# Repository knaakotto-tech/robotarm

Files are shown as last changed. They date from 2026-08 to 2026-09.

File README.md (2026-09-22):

# robotarm

**C++ control software for a custom 5-DOF robotic arm, written from scratch — no vendor SDK.**






<!-- TODO: drop a photo or a short GIF of the arm here -->
<!-- ![The arm](docs/arm.jpg) -->

---

## What this is

A 5-servo robotic arm driven by Feetech STS3215 bus servos on a Raspberry Pi 5.
Mechanics, CAD and control software are all my own work.

The point of the project is the software. Feetech ships an SDK; this repository
deliberately does not use it. Every layer — serial port setup, packet framing,
checksums, register access, joint math — is implemented here, so that each byte
on the wire is something I can explain.

## Architecture

Each layer only talks to the one directly below it. The bottom is an abstract
interface, which is what makes everything above it testable without hardware.

```mermaid
flowchart TD
    A["apps/ — ping, move_test, calibrate_middle, measure_limits, ..."] --> B["Joint — degrees ↔ ticks, software limits"]
    A --> C["ServoBus — read_register / write_register"]
    B -.-> C
    C --> D["protocol — build_packet / parse_response / checksum"]
    D --> E["Transport (abstract) — write / read"]
    E --> F["SerialTransport — termios, 1 Mbit/s, 8N1"]
    E --> G["MockTransport — hex dump + canned replies"]
```

`MockTransport` is not a testing afterthought: it prints the exact bytes a command
would put on the bus and returns a prepared answer. When a servo goes quiet, running
the same sequence against the mock says immediately whether the problem is in the
code or in the hardware.

The `Joint` layer is currently pure math (dashed arrow). The `Arm` layer that
coordinates several joints over one bus is the next piece.

## Wire protocol

Feetech servos speak a Dynamixel-style protocol over a half-duplex serial bus:

```
0xFF 0xFF   ID   LENGTH   INSTRUCTION   PARAM ...   CHECKSUM
```

* `LENGTH` = number of parameters + 2
* `CHECKSUM` = bitwise complement of the sum of all bytes from `ID` onwards
  (the two header bytes are not included)

Instructions used so far: `0x01` PING, `0x02` READ, `0x03` WRITE.

Register addresses and their widths live in
[`include/robotarm/registers.hpp`](include/robotarm/registers.hpp) as named
constants — `R_GOAL_POSITION` instead of `42`, with the width carried alongside
the address so the bus layer can reject a malformed write before it is sent.

## Hardware

| Part | Detail |
| --- | --- |
| Servos | 5× Feetech STS3215 (12 V, C018, 1:345), IDs 1–5 |
| Bus adapter | Waveshare Bus Servo Adapter A, USB mode → `/dev/ttyACM0` |
| Controller | Raspberry Pi 5 |
| Power | 12 V / 5 A |
| Mechanics | Custom design, printed on a Bambu Lab A1 |

## Repository layout

```
robotarm/
├── include/robotarm/   # headers — what a class can do
├── src/                # implementation — how it does it
├── apps/               # small executables, one per experiment
├── cad/                # OpenSCAD models (servo library, fit test)
└── CMakeLists.txt
```

## Build and run

```bash
git clone https://github.com/knaakotto-tech/robotarm.git
cd robotarm
cmake -B build
cmake --build build
```

Targets that need no hardware — these run anywhere:

```bash
./build/mock_test        # dumps the bytes a command would send
./build/protocol_test    # checksum, packet building, joint math
./build/bus_test         # ServoBus against MockTransport
```

Targets that need a connected servo bus:

```bash
./build/ping              # ping servo ID 1
./build/move_test         # enable torque, drive to both ends, read position back
./build/calibrate_middle  # re-centre a servo on its mechanical middle
./build/measure_limits    # torque off, move a joint by hand, record min/max ticks
```

On Linux the user needs access to the serial device:

```bash
sudo usermod -aG dialout $USER   # then log out and back in once
```

On macOS use the `/dev/cu.*` device, never `/dev/tty.*` — the latter blocks on
open while waiting for a modem signal that never arrives.

## Status

- [x] `Transport` interface + `MockTransport`
- [x] `SerialTransport` (termios, 1 Mbit/s, raw mode, 100 ms read timeout)
- [x] Protocol layer — packet building, checksum, response parsing
- [x] Register map with address + width
- [x] `ServoBus` — read/write registers, verified against live servos
- [x] Servo IDs 1–5 assigned and commissioned
- [x] Joint layer — `degrees_to_ticks` / `ticks_to_degrees`, round-trip tested
      across the full angle range and both directions
- [x] All five servos re-centred with the built-in middle-point calibration
- [x] Tool to measure the real travel range of each joint by hand
- [ ] Per-joint limits filled in from the measurements
- [ ] Move to a defined rest position before torque is released
- [ ] `Arm` layer — several joints, synchronised writes
- [ ] Interpolation and kinematics
- [ ] Input layer (gamepad or web UI)

## Design notes

A few decisions that shaped the rest of the code:

* **Structured return types, not `bool`.** `read_register` returns a `Response`
  carrying id, error byte, payload and a validity flag; `degrees_to_ticks` returns
  a `TickResult`. The caller decides what to do with a failure — nothing is
  clamped silently and nothing throws.
* **Length checks before indexing.** In `parse_response`, the `size() < 6` guard
  has to come before comparing against the length byte, otherwise the subtraction
  wraps around on an unsigned type and a short reply passes as valid.
* **The zero point lives in the servo, not in software.** All five servos were
  re-centred using the STS3215's built-in middle-point calibration, so `zero_ticks`
  is 2048 for every joint and that position is the arm standing upright. Joints 2
  and 3 travel more than 180°, which would otherwise have put the 4095 → 0 tick
  wraparound in the middle of their working range. Repositioning the servo horn
  mechanically would have achieved the same, but has to be redone whenever a
  bracket changes.
* **Software end stops live in the joint layer.** A joint driven past its
  mechanical limit works ~30 kg·cm against its own bracket. The limit check
  happens before a packet is ever built.
* **`ServoBus` holds a `Transport&`.** A bus without a transport is not a state
  worth representing, so the reference member makes it impossible to construct one.

## References

* Feetech STS3215 datasheet (ST-3215-C018) — register map and protocol
* Waveshare Bus Servo Adapter A documentation

## License

Licensed under the Apache License 2.0 — see [LICENSE](LICENSE).

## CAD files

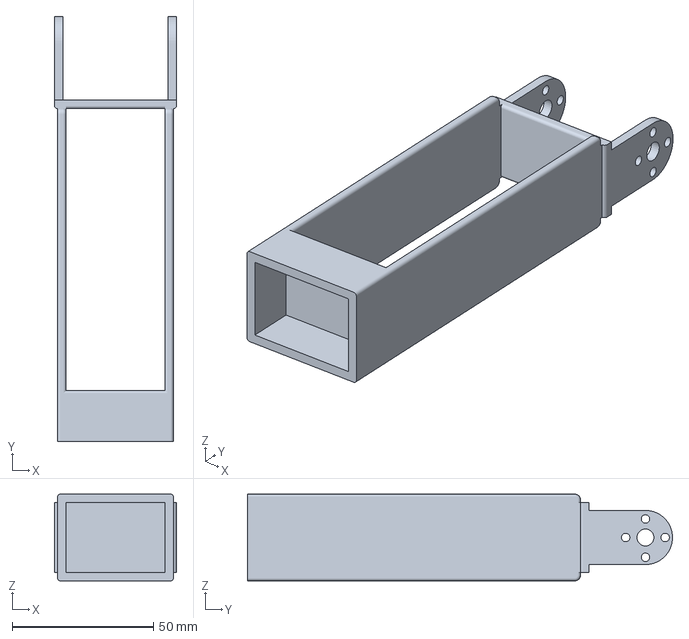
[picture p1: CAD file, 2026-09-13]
cad/zusammmengesetzterArmTeil-Assembly.3mf
43.3 x 150.6 x 30.7 mm

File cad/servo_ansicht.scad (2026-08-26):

// =====================================================================
//  servo_ansicht.scad  --  nur zum Anschauen
//
//  sts3215.scad ist eine Bibliothek und zeichnet absichtlich nichts.
//  Diese Datei bindet sie ein und ruft die Module auf, damit du das
//  Modell sehen kannst. Sie geht nie in ein Bauteil ein.
// =====================================================================

include <sts3215.scad>

// Der Servo
sts3215();

// Wellenachse: der Ursprung des Koordinatensystems
color("red")
    translate([0, 0, -SERVO_H - 12])
        cylinder(d = 1.0, h = SERVO_H + 26);

// Die vier Montageloecher an ihrer berechneten Position
color("blue")
    sts3215_loecher(tiefe = SERVO_H + 20, d = HOLE_D);

// Das Lochbild des Servohorns, auf der Wellenseite
color("green")
    translate([0, 0, SHAFT_H])
        horn_loecher(tiefe = 6);

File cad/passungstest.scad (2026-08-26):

// =====================================================================
//  passungstest.scad  --  Teil 1
//
//  Zweck: herausfinden, wie viel Spiel dein Drucker braucht, damit der
//  STS3215 saugend in einer Tasche sitzt.
//
//  Drei Taschen mit unterschiedlichem Spiel nebeneinander. Einmal
//  drucken, den Servo in allen dreien probieren. Die Tasche, in die er
//  ohne Werkzeug reingeht und in der er nicht wackelt, gewinnt.
//  Diesen Wert traegst du dann in sts3215.scad bei FIT ein -- ab da
//  passt jede Halterung, die wir daraus bauen.
//
//  Warum ueberhaupt Spiel noetig ist: ein 3D-Drucker legt heissen
//  Kunststoff ab. Beim Abkuehlen schrumpft er, und an Innenecken
//  quillt Material leicht nach innen. Eine Tasche, die im Modell exakt
//  45.23 mm hat, kommt real bei etwa 44.9 raus -- der Servo geht nicht
//  rein. Wie stark der Effekt ausfaellt, haengt an Duese, Material und
//  Temperatur und ist deshalb bei jedem Drucker anders. Man misst es
//  einmal aus, statt zu raten.
// =====================================================================

include <sts3215.scad>

SPIELE  = [0.15, 0.30, 0.45];   // getestete Werte, Spiel pro Seite in mm

WAND    = 3.2;    // Wandstaerke rund um jede Tasche
LABEL   = 9;      // Streifen an der Vorderseite fuer die Beschriftung
HOEHE   = 12;     // Bauteilhoehe; reicht zum Beurteilen und spart Zeit
SCHRIFT = 5;      // Schriftgroesse
GRAVUR  = 0.6;    // Gravurtiefe

// Breite einer Zelle und laufender Versatz
function zell_breite(i) = SERVO_L + 2*SPIELE[i] + 2*WAND;
function versatz(i)     = (i <= 0) ? 0 : versatz(i-1) + zell_breite(i-1);

// ---------------------------------------------------------------------
//  Eine Zelle: Rahmen mit durchgehender Tasche und Beschriftung
// ---------------------------------------------------------------------
module zelle(spiel) {
    tasche_l = SERVO_L + 2*spiel;
    tasche_w = SERVO_W + 2*spiel;
    aussen_l = tasche_l + 2*WAND;
    aussen_w = tasche_w + 2*WAND + LABEL;

    difference() {
        cube([aussen_l, aussen_w, HOEHE]);

        // Tasche geht durch: so kannst du den Servo wieder
        // rausdruecken, statt ihn rauszuhebeln
        translate([WAND, LABEL + WAND, -1])
            cube([tasche_l, tasche_w, HOEHE + 2]);

        // Wert in die Oberseite gravieren
        translate([aussen_l/2, LABEL/2, HOEHE - GRAVUR])
            linear_extrude(GRAVUR + 1)
                text(str(spiel), size = SCHRIFT,
                     halign = "center", valign = "center");
    }
}

for (i = [0 : len(SPIELE) - 1])
    translate([versatz(i), 0, 0])
        zelle(SPIELE[i]);

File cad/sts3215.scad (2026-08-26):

// =====================================================================
//  sts3215.scad  --  Bibliothek: Feetech STS3215 (Variante C018)
//
//  Diese Datei zeichnet von sich aus nichts. Sie stellt nur Konstanten
//  und Module bereit, die andere Dateien per include einbinden.
//  Genau wie ein Header in C++: er sagt, was es gibt, aber er ist kein
//  Programm.
//
//  Das Servo-Modell ist kein Detailabbild, sondern die Huellkontur.
//  Fuer eine Halterung ist genau das richtig -- die Tasche muss den
//  groessten Querschnitt aufnehmen, die Kuehlrippen interessieren nicht.
//
//  Koordinaten-Ursprung: Wellenachse, auf Hoehe der Gehaeuseflaeche
//    +Z = Richtung der Abtriebswelle
//    +X = Laengsrichtung, weg vom Getriebe (zum Motorende)
//    +Y = Breite
//
//  Der Ursprung liegt bewusst auf der Wellenachse: das ist die
//  Gelenkachse. Dreht sich ein Bauteil um dieses Gelenk, ist rotate()
//  um Z dann ohne Umrechnerei richtig.
//
//  Quelle: Feetech Datenblatt ST-3215-C018, Edition A/0, 2023-07-20
//          (liegt im Repo unter docs/FT01015.pdf)
// =====================================================================

$fn = 64;

// ---------------------------------------------------------------------
//  Gesichert: im Datenblatt bemasst
// ---------------------------------------------------------------------
SERVO_L      = 45.23;   // Laenge (Waveshare-Blatt: 45.22)
SERVO_W      = 24.73;   // Breite
SERVO_H      = 35.0;    // Hoehe des Gehaeuses
SHAFT_D      = 5.90;    // Verzahnung 25T, Aussendurchmesser
SHAFT_H      = 3.40;    // ragt ueber die Gehaeuseflaeche hinaus
IDLER_D      = 6.00;    // Gegenlager auf der Gegenseite
IDLER_H      = 4.10;    // ragt ueber die Gehaeuseflaeche hinaus

// Abgeleitet: das Datenblatt bemasst 12.5 von der Gehaeusemitte
// zur Wellenachse, nicht von einer Kante.
SHAFT_OFFSET = SERVO_L/2 - 12.5;   // = 10.115; Waveshare bemasst 10.11 direkt

// ---------------------------------------------------------------------
//  Servohorn (die Metallscheibe), Datenblatt Abschnitt 11
// ---------------------------------------------------------------------
HORN_D       = 19.95;   // Aussendurchmesser
HORN_BOHR    = 14.0;    // Lochkreisdurchmesser der 4 Loecher
HORN_LOCH_D  = 3.2;     // Lochdurchmesser, fuer M3
HORN_DICKE   = 2.1;     // Blechstaerke der flachen Variante

// ---------------------------------------------------------------------
//  Montageloecher, aus der Waveshare-Masszeichnung (ST3215-Gehaeuse)
//  Masskette der Draufsicht: 18.41 + 20.7 + 6.11 = 45.22
//  Die beiden inneren Linien laufen durch die Lochreihen.
// ---------------------------------------------------------------------
HOLE_DX       = 20.7;   // Lochabstand laengs (bemasst)
HOLE_DY       = 20.7;   // Lochabstand quer (aus der Zeichnung gemessen)
HOLE_D        = 2.5;    // Kernloch fuer PA3.0 selbstschneidend

// Mitte des Lochbilds, gemessen von der Wellenachse Richtung Motorende:
//   erste Lochreihe  18.41 - 10.11 = 8.30 hinter der Welle
//   Mitte            8.30 + 20.7/2 = 18.65
HOLE_CENTER_X = 18.41 - SHAFT_OFFSET + HOLE_DX/2;

// ---------------------------------------------------------------------
//  Spiel fuer Taschen -- mit passungstest.scad am A1 ermittelt
// ---------------------------------------------------------------------
FIT = 0.15;

// =====================================================================
//  Der Servo als Volumen
// =====================================================================
module sts3215(spiel = 0) {
    l = SERVO_L + 2*spiel;
    w = SERVO_W + 2*spiel;
    h = SERVO_H + 2*spiel;

    translate([-SHAFT_OFFSET - spiel, -w/2, -h])
        cube([l, w, h]);

    cylinder(d = SHAFT_D, h = SHAFT_H);              // Abtriebswelle

    translate([0, 0, -h - IDLER_H])                  // Gegenlager
        cylinder(d = IDLER_D, h = IDLER_H);
}

// =====================================================================
//  Die vier Montageloecher als Bohrwerkzeug (fuer difference())
// =====================================================================
module sts3215_loecher(tiefe = 8, d = HOLE_D) {
    for (sx = [-1, 1], sy = [-1, 1])
        translate([HOLE_CENTER_X + sx*HOLE_DX/2, sy*HOLE_DY/2, -tiefe/2])
            cylinder(d = d, h = tiefe);
}

// =====================================================================
//  Das Lochbild des Servohorns als Bohrwerkzeug
// =====================================================================
module horn_loecher(tiefe = 8, d = HORN_LOCH_D) {
    for (i = [0 : 3])
        rotate([0, 0, i * 90])
            translate([HORN_BOHR/2, 0, -tiefe/2])
                cylinder(d = d, h = tiefe);
}

// ---------------------------------------------------------------------
//  Zum Anschauen: die naechste Zeile voruebergehend einkommentieren.
//  Vor dem Einbinden in andere Teile wieder auskommentieren.
// ---------------------------------------------------------------------
// sts3215();

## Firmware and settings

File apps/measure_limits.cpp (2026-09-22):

#include <robotarm/registers.hpp>
#include <robotarm/protocol.hpp>
#include <robotarm/serial_transport.hpp>
#include <robotarm/servo_bus.hpp>
#include <iostream>
#include <cstdio>
#include <chrono>
#include <thread>


//für er eignis feststellung für die while schliefe zu beenden
#include <poll.h>
#include <unistd.h>




int main(int argc, char* argv[]){

    if(argc < 3){return 1;}

    pollfd tastatur{};
    tastatur.fd = STDIN_FILENO;   // welcher Deskriptor
    tastatur.events = POLLIN;     // was dich interessiert: "gibt es was zu lesen?"

    int ereignis = poll(&tastatur, 1 ,0);

    int id_servo = std::atoi(argv[2]);

    robotarm::SerialTransport serial(argv[1]);
    robotarm::ServoBus bus(serial);

    int max = 0;
    int min = 4096;

    bus.write_register(id_servo, robotarm::R_TORQUE_ENABLE, {0});

    while(ereignis == 0) {
        //Schaut ob etwas sich am ereignis geändert hat (tastendruck)
        ereignis = poll(&tastatur, 1 ,0);
        std::this_thread::sleep_for(std::chrono::milliseconds(50));
        
        robotarm::Response r = bus.read_register(id_servo, robotarm::R_PRESENT_POSITION);

        if(r.data.size() < 2 || r.valid == false){continue;}
        
        if(max < robotarm::to_uint16(r.data[0], r.data[1])){max = robotarm::to_uint16(r.data[0], r.data[1]);}
        if(min > robotarm::to_uint16(r.data[0], r.data[1])){min = robotarm::to_uint16(r.data[0], r.data[1]);}

        printf("\rServo %d:Max ticks: %4d - Min ticks: %4d", id_servo ,max, min);
        fflush(stdout);
        
    }

    printf("\n");

    return 0;
}

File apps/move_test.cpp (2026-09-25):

#include <robotarm/servo_bus.hpp>
#include <robotarm/protocol.hpp>
#include <robotarm/serial_transport.hpp>
#include <robotarm/registers.hpp>
#include <cstdio>
#include <thread>
#include <chrono>
#include <robotarm/arm_config.hpp>
#include <poll.h>
#include <unistd.h>
#include <robotarm/joint.hpp>



void print_read(const robotarm::Response& r) {
    
    if(r.valid == true) {
        printf("valid=%d station=", r.valid);
        printf("Ticks: %d", robotarm::to_uint16(r.data[0], r.data[1]));
    } else{
        printf("unvollsänding => %d ", r.valid);

        std::printf("RX: %zu Bytes\n", r.data.size()); 

    }

    printf("\n");
}


void set_print_position(int16_t winkel, robotarm::ServoBus& bus, int id_eingabe){
    
    robotarm::Response r = bus.read_register(id_eingabe, robotarm::R_PRESENT_POSITION);

    print_read(r);

    const robotarm::Joint& joint = robotarm::joint_by_id(id_eingabe);

    robotarm::TickResult ziel = robotarm::degrees_to_ticks(joint, winkel);

    if(!ziel.valid){
        printf("Winkel %d ligt nicht in den voegeschirebeden grenzen von gelenk %d\n", winkel, joint.servo_id);
        return;
    }

    bus.write_register(id_eingabe, robotarm::R_GOAL_POSITION, robotarm::to_low_high(ziel.ticks));
    std::this_thread::sleep_for(std::chrono::milliseconds(400));

    bool position_ready = true;

    //notfall tastedrücke und es bricht die schleife ab
    pollfd tastatur{};
    tastatur.fd = STDIN_FILENO;
    tastatur.events = POLLIN;

    while(position_ready){
        std::this_thread::sleep_for(std::chrono::milliseconds(100));
        r = bus.read_register(id_eingabe, robotarm::R_PRESENT_POSITION);

        int tasten_druck = poll(&tastatur, 1, 0);

        if(tasten_druck > 0){
            printf("Tastendruck erkannt, winkel: %d wurde abgebrochen\n", winkel);
            position_ready = false;
        }

        if (r.valid == false){continue;}

        if(robotarm::to_uint16(r.data[0], r.data[1]) >= ziel.ticks -5 && robotarm::to_uint16(r.data[0], r.data[1]) <= ziel.ticks +5 ){position_ready = false;}


        

    }
    return print_read(r);

}


int main(int argc, char* argv[]) {

    if(argc < 3){
        printf("Fehler beim port aufrufen: %s", argv[0]);
        return 1;
    }

    robotarm::SerialTransport serial(argv[1]);
    robotarm::ServoBus bus(serial);


    int id_eingabe = std::atoi(argv[2]);

    robotarm::joint_by_id(id_eingabe);

    bus.write_register(id_eingabe, robotarm::R_GOAL_SPEED, robotarm::to_low_high(100));
    bus.write_register(id_eingabe, robotarm::R_ACCELERATION, {50});


    set_print_position(20, bus, id_eingabe);

    set_print_position(0, bus, id_eingabe);

    set_print_position(-20, bus, id_eingabe);


}

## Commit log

2026-08-19 Projektstruktur und minimaler Build
2026-08-21 Transport-Schicht: abstrakte Basis und MockTransport
2026-08-24 Antwortpaket zerlegen und Prüfsumme kontrollieren
2026-08-24 CMake: mock_test und protocol_test als eigene Targets
2026-08-26 Aussagekräftige und Fehler abfangen
2026-08-26 cad: STS3215-Dummy aus dem Datenblatt
    [sts3215.scad]
2026-08-26 SerialTransport: termios konfiguriert
    [passungstest.scad]
2026-08-26 bytes umwandlung von 8 zu 16 und zurück
2026-08-26 cad: Lochbild und Passung 0.15 aus Waveshare-Zeichnung
    [sts3215.scad]
2026-08-26 cad: Ansichtsdatei zum Anschauen des Servo-Modells
    [servo_ansicht.scad]
2026-08-31 protocol verbessert und ServoBus gebaut
2026-08-31 test für bewegung der Motoren
2026-09-01 read_register fertig gestellt also antworten von servo lesen
2026-09-01 test zum auslesen der Motoren
2026-09-02 register überarbeitet (adresse und länge kommen zusammen mit) und angepasst in servo bus zur weiter verarbeitung
2026-09-12 Joint fertig gestellt und programm gebaut um die postion der motor einzustellen um den Arm zu kalibrieren
2026-09-13 Revise README with detailed project information
    Expanded project overview and details about architecture, wire protocol, hardware, and repository layout.
2026-09-13 First 3D model for an arm part
    [zusammmengesetzterArmTeil-Assembly.3mf]
2026-09-22 Tool für das winken herrausfinden der Servos
2026-09-22 Revise README with project details and command updates
    Updated project details, added new commands, and clarified power distribution.
2026-09-25 arm_config geschrieben, alle gerenzwerte sind dort eingetragen für die Servos und erstes Test programm für arm in move-test geschrieben
2026-09-25 joint.cpp zu move_test hinzugefuegt
2026-09-25 move_test fix da es bei negative zahlen nicht funktioiert hat und bessere Lesbarkeit in ticks
    [move_test.cpp]
2026-10-02 arm classe erstellt um später eine ruhepose einzufühgen und robotarm library in cmakelist hinzugefühgt
2026-10-03 arm.hpp vorbereitet
